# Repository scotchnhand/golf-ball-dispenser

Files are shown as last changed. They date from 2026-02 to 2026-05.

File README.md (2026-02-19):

# Golf Ball Dispenser

An automated golf ball dispenser that detects when you're ready and feeds a ball on demand. Built with 3D printed parts, an Arduino Nano, and off-the-shelf components.
https://youtu.be/GQfpbspkEQ4
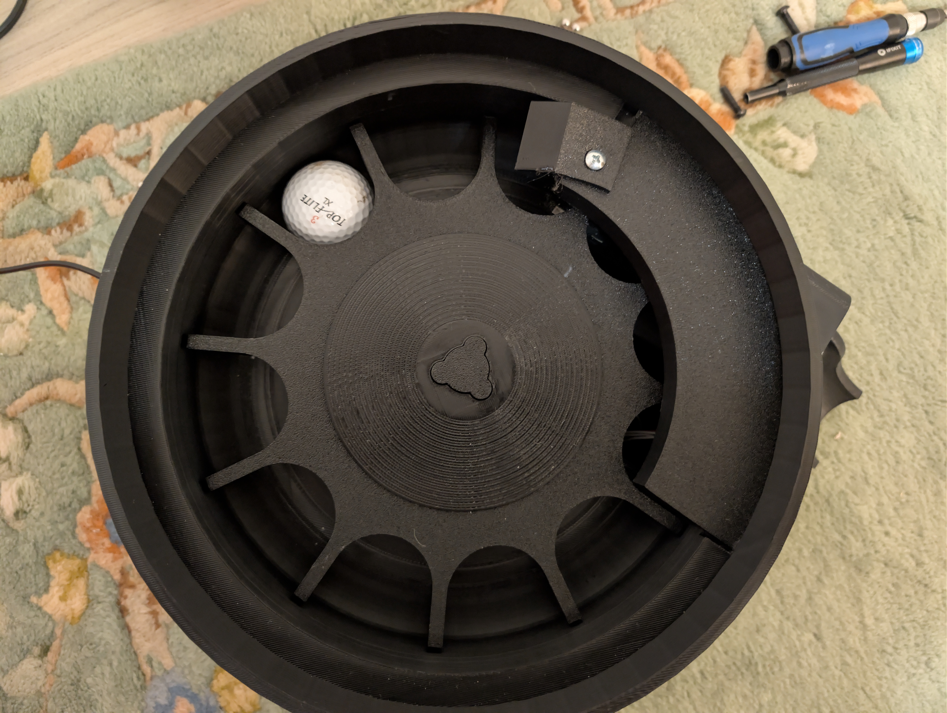
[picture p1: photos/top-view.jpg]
Top View

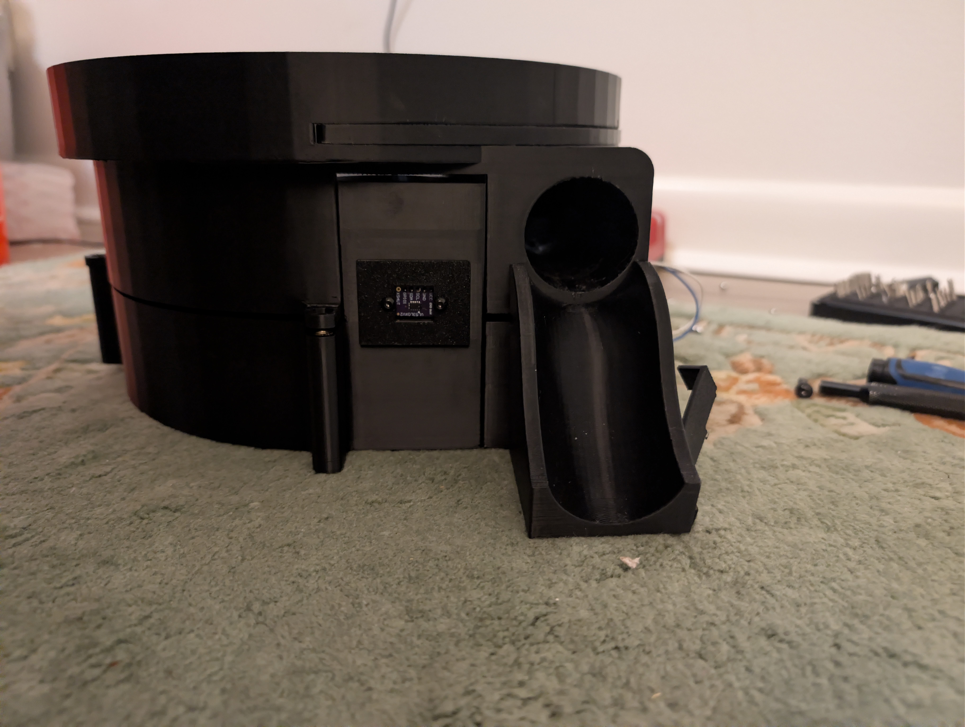
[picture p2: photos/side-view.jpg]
Side View


## How It Works

1. A **VL53L0X Time-of-Flight laser distance sensor** detects when an object (your club or hand) is within 20cm
2. A **DC geared motor** spins a carousel that feeds a single golf ball to the exit chute
3. A **limit switch** detects when the carousel has completed one rotation and stops the motor
4. The system resets and waits for the next trigger

### Safety Features

- **10-second timeout**: Motor stops automatically if the limit switch isn't triggered within 10 seconds
- **Debounced inputs**: Both the limit switch and distance sensor readings are debounced to prevent false triggers
- **Interrupt-driven**: Limit switch uses hardware interrupt for immediate motor stop
- **Limit switch pre-press detection**: If the limit switch is already pressed when a cycle starts, the system waits for it to release before watching for the stop signal

## Wiring Diagram

| Component | Pin | Arduino Nano |
|---|---|---|
| Limit Switch | Signal | D2 |
| VL53L0X | GPIO1 (interrupt) | D3 |
| L298N | IN1 | D5 |
| L298N | IN2 | D6 |
| VL53L0X | SDA | A4 |
| VL53L0X | SCL | A5 |
| VL53L0X | VIN | 5V |
| VL53L0X | GND | GND |
| L298N | 12V | External 12V PSU |
| L298N | GND | Common GND |
| Limit Switch | COM | GND |
| Limit Switch | NO | D2 (uses internal pull-up) |

## Bill of Materials

> **Note:** Many of these parts are interchangeable and can be found on Amazon, eBay, or any electronics supplier. The AliExpress links below are what was used in this build. Prices shown are approximate per-unit costs (many listings sell in multi-packs, so buying just one may cost more).

### Electronics

| # | Component | Qty | Approx. Unit Price | Link |
|---|---|---|---|---|
| 1 | Arduino Nano (ATmega328P) | 1 | ~$2.50 | [AliExpress](https://www.aliexpress.us/item/3256806444439267.html) |
| 2 | L298N Motor Driver Module | 1 | ~$1.50 | [AliExpress](https://www.aliexpress.us/item/3256807078618738.html) |
| 3 | VL53L0X ToF Distance Sensor | 1 | ~$1.80 | [AliExpress](https://www.aliexpress.us/item/3256806179489186.html) |
| 4 | Low RPM DC Geared Motor (12V) | 1 | ~$12.00 | [AliExpress](https://www.aliexpress.us/item/3256805899293106.html) |
| 5 | Micro Limit Switch | 1 | ~$0.20 | [AliExpress](https://www.aliexpress.us/item/3256806027015669.html) |
| 6 | ON/OFF Rocker Switch | 1 | ~$0.30 | [AliExpress](https://www.aliexpress.us/item/2251832837763800.html) |
| 7 | DC Barrel Jack Panel Mount | 1 | ~$0.30 | [AliExpress](https://www.aliexpress.us/item/3256804296022885.html) |
| 8 | 12V 1A AC-DC Power Adapter | 1 | ~$3.00 | [AliExpress](https://www.aliexpress.us/item/3256804346592962.html) |
| 9 | Small Prototype PCB Board | 1 | ~$0.25 | [AliExpress](https://www.aliexpress.us/item/3256801518277095.html) |

### Hardware

| # | Component | Qty | Approx. Unit Price | Link |
|---|---|---|---|---|
| 10 | M5 Heat-Set Inserts (brass) | 7 | ~$0.10 ea | [AliExpress](https://www.aliexpress.us/item/3256809271320211.html) |
| 11 | M5 Screws | 7 | ~$0.05 ea | [AliExpress](https://www.aliexpress.us/item/3256802218134509.html) |
| 12 | M4 Screw + Nut | 1 | ~$0.05 | [AliExpress](https://www.aliexpress.us/item/3256802218134509.html) |
| 13 | M3 Screws | 2 | ~$0.05 ea | [AliExpress](https://www.aliexpress.us/item/3256802218134509.html) |
| 14 | 6mm Steel Ball Bearings / BBs | ~20+ | ~$0.02 ea | [AliExpress](https://www.aliexpress.us/item/3256805859138836.html) |
| 15 | Epoxy | 1 | ~$2.00 | - |

### Wiring / Consumables

| # | Component | Qty | Notes |
|---|---|---|---|
| 16 | JST XH Connectors | 1 set | [AliExpress](https://www.aliexpress.us/item/3256806179489186.html) |
| 17 | Hook-up Wire / Jumper Wire | assorted | Any silicone or dupont wire |
| 18 | Solder | - | Lead-free recommended |

**Estimated total cost: ~$18 - $25** (buying individual components)

> Prices fluctuate on AliExpress. Many of these components are sold in multi-packs, so the per-unit cost can be much lower if you're building multiple units or want spares.

### Tools Required

- **3D Printer** (for printing the enclosure and carousel)
- **Soldering iron** (for heat-set inserts and wiring)
- **Basic hand tools** (screwdrivers, wire strippers)

## 3D Printed Parts

The CAD model is provided as a STEP file (`golfballdispenser.STEP`) which can be opened in any CAD software (Fusion 360, FreeCAD, SolidWorks, etc.). A PDF drawing is also included (`Ball dispenser.pdf`).

### Print Settings (Recommended)

- **Material**: PLA or PETG
- **Layer Height**: 0.2mm
- **Infill**: 15-20%
- **Supports**: Yes (for the exit chute and motor mount)

## Software Setup

### Arduino IDE

1. Open `golf_feeder.ino` in Arduino IDE
2. Install the required library:
   - Go to **Sketch > Include Library > Manage Libraries**
   - Search for **"VL53L0X"** by **Pololu**
   - Install it
3. Select **Board**: Arduino Nano
4. Select **Processor**: ATmega328P (Old Bootloader) if upload fails
5. Upload

### Configurable Parameters

| Parameter | Default | Description |
|---|---|---|
| `TRIGGER_DISTANCE_MM` | 200 | Detection distance in mm (20cm) |
| `MOTOR_TIMEOUT_MS` | 10000 | Safety timeout in ms (10 seconds) |
| `COOLDOWN_TIME_MS` | 500 | Delay before accepting next trigger |
| `SENSOR_READ_INTERVAL_MS` | 100 | Fallback polling interval in ms |

## Photos

See the [photos/](photos/) directory for build photos showing the assembled unit, wiring, and internal components.

## License

This project is open source. Feel free to build, modify, and share.

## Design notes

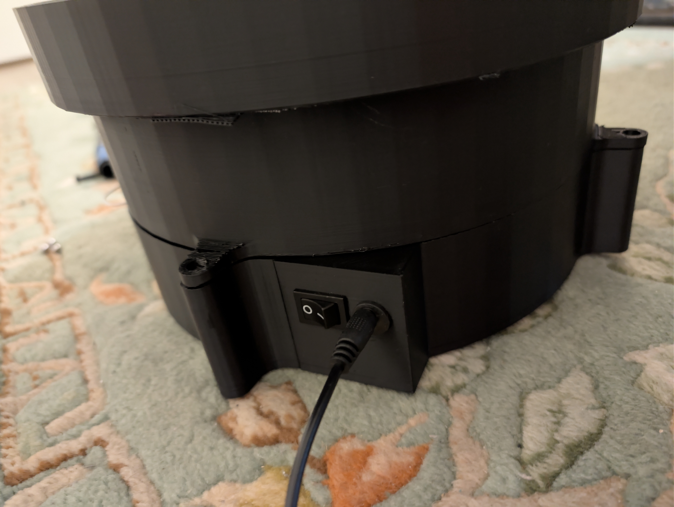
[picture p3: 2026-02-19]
photos/power-input.jpg

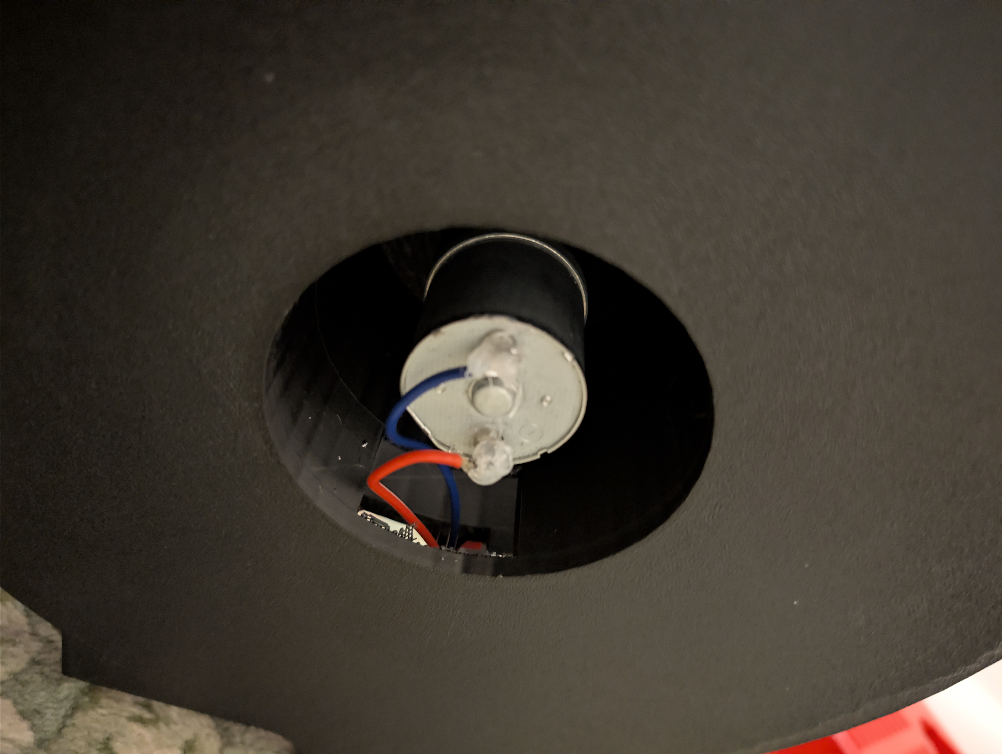
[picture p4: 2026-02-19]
photos/motor-mount.jpg

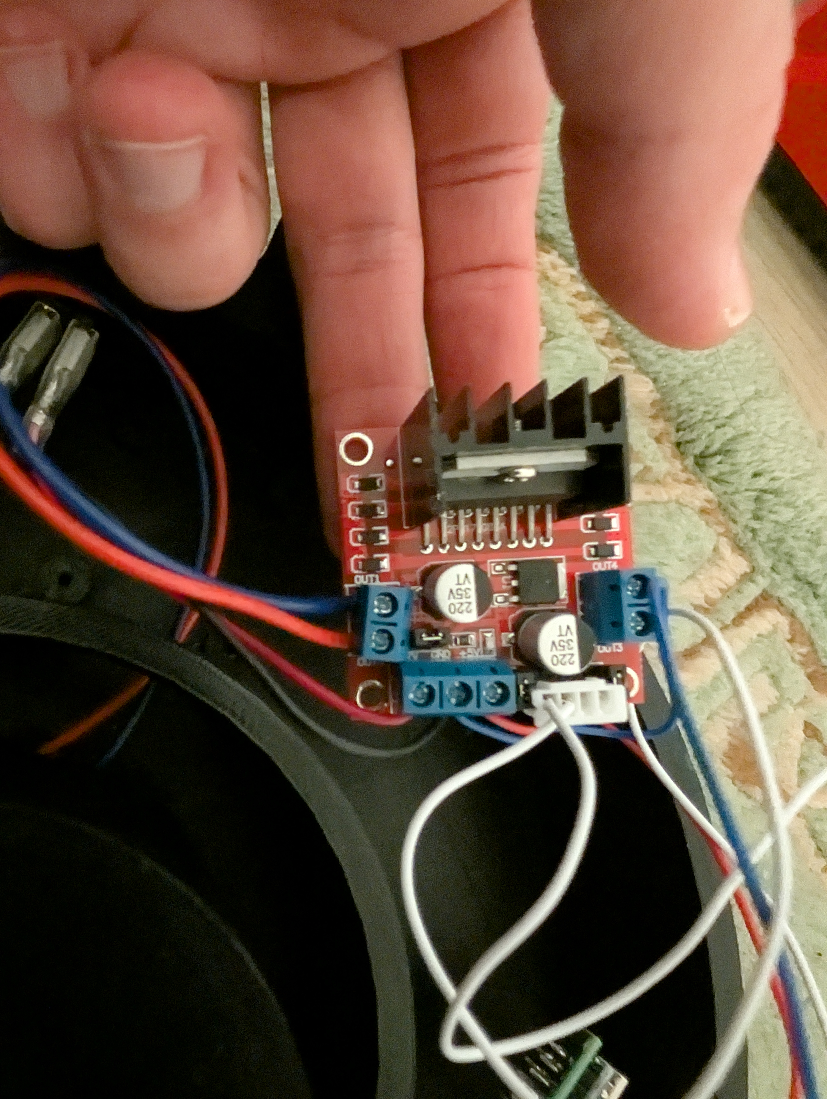
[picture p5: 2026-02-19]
photos/l298n-driver.jpg

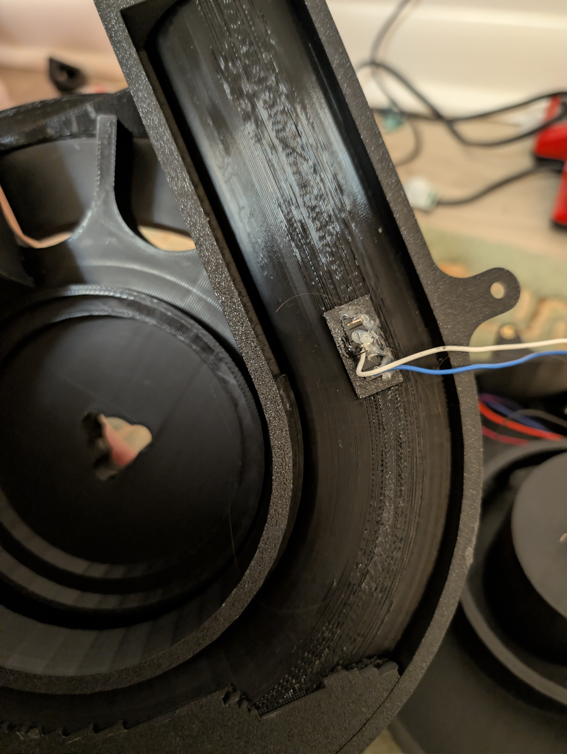
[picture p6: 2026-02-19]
photos/limit-switch-detail.jpg

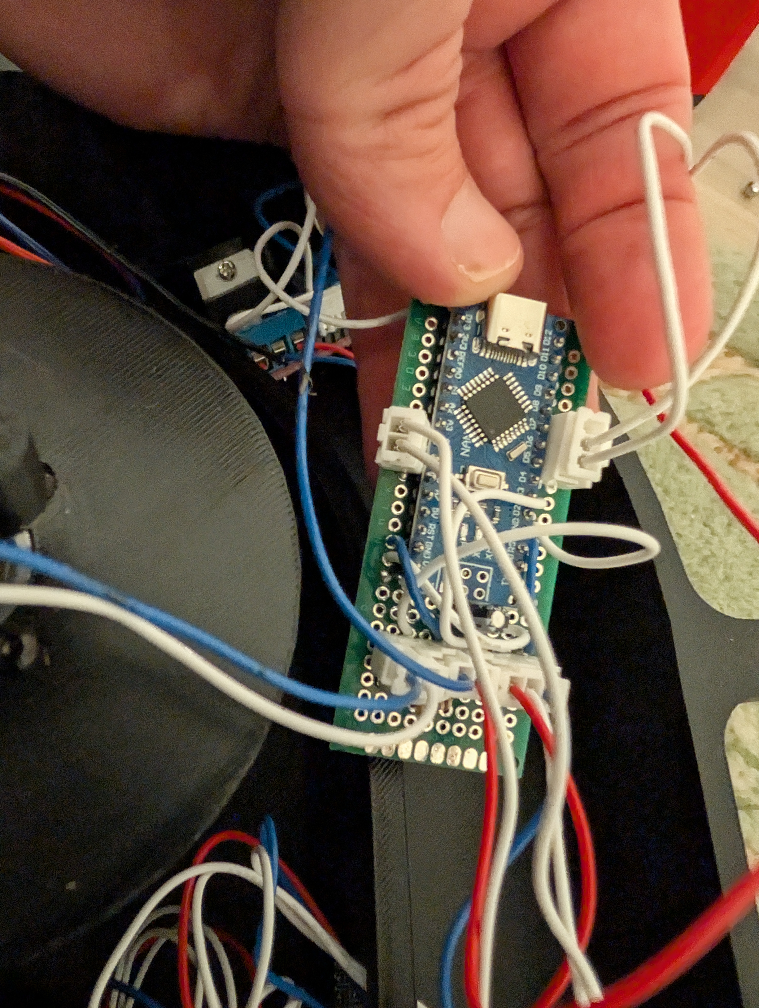
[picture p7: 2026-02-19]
photos/arduino-nano.jpg

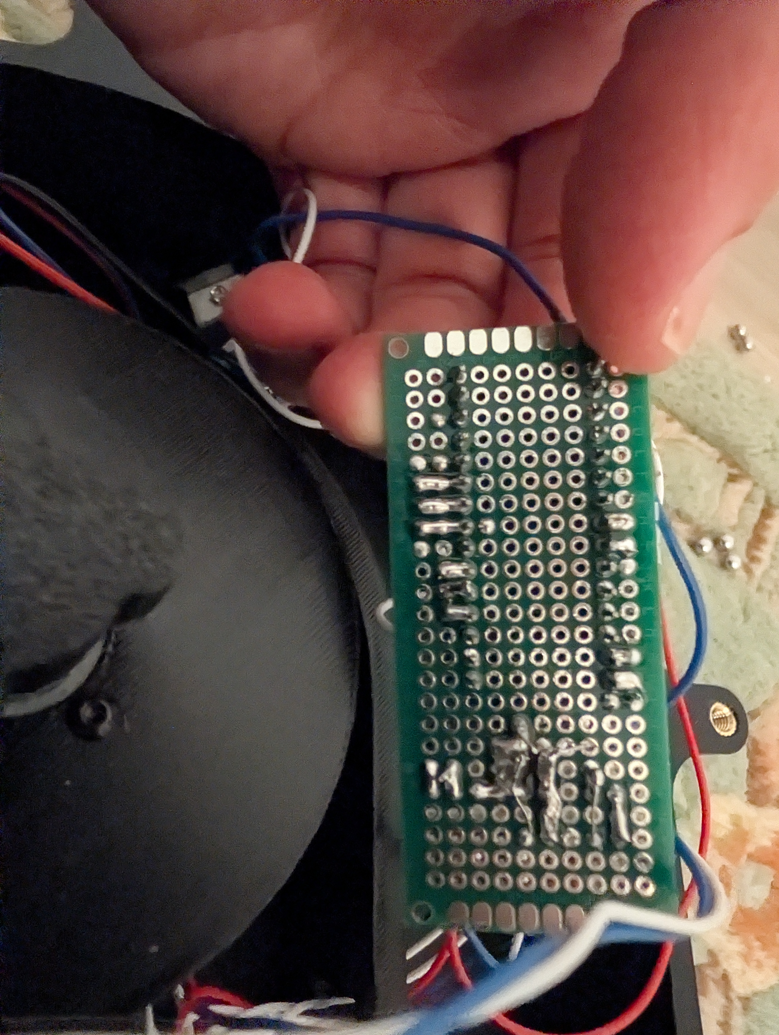
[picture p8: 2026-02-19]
photos/perfboard.jpg

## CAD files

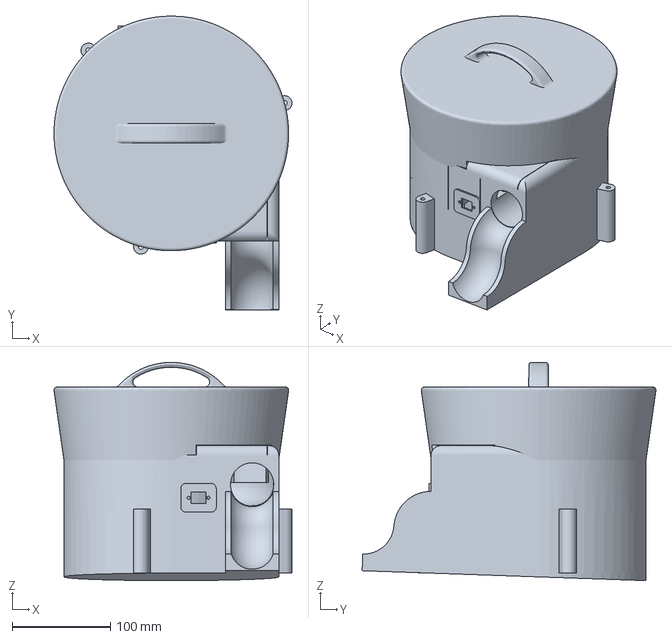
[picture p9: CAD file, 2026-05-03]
Golf ball dispenser less than256 mm.3MF
241.6 x 298.3 x 221.6 mm

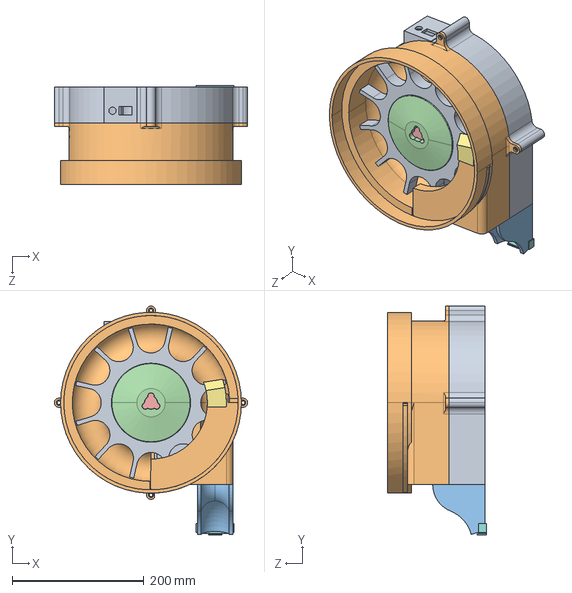
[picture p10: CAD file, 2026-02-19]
golfballdispenser.STEP
294.0 x 348.1 x 150.0 mm

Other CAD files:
dispenser.FCStd

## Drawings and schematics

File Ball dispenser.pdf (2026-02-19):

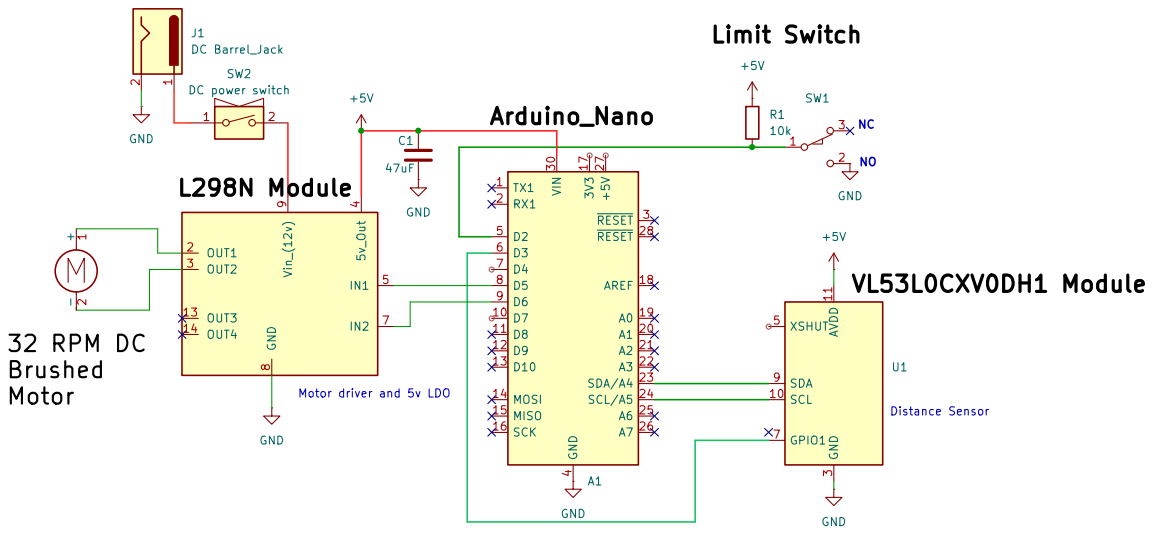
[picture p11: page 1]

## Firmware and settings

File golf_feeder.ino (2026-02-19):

/*
 * Automated Golf Ball Feeder
 *
 * Hardware:
 *   - Arduino Nano
 *   - Limit switch on D2 (INPUT_PULLUP - normally HIGH, LOW when pressed)
 *   - L298N Motor Driver: IN1=D5, IN2=D6
 *   - VL53L0X ToF Distance Sensor:
 *       - I2C: SDA=A4, SCL=A5
 *       - GPIO1 (interrupt) → D3
 *
 * Operation:
 *   - Object detected within 20cm → motor runs
 *   - Limit switch pressed → motor stops immediately
 *   - 10 second timeout safety if limit switch not triggered
 *
 * Library: Install "VL53L0X" by Pololu from Library Manager
 */

#include <Wire.h>
#include <VL53L0X.h>

// Pin definitions
const int PIN_LIMIT_SWITCH = 2;
const int PIN_SENSOR_INT = 3;   // VL53L0X GPIO1 interrupt pin
const int PIN_MOTOR_IN1 = 5;
const int PIN_MOTOR_IN2 = 6;

// Distance threshold (in mm)
const int TRIGGER_DISTANCE_MM = 200;  // 20cm = 200mm

// Timing constants
const unsigned long DEBOUNCE_DELAY_MS = 50;
const unsigned long MOTOR_TIMEOUT_MS = 10000;  // 10 second safety timeout
const unsigned long COOLDOWN_TIME_MS = 500;    // Time to ignore sensor after cycle

// Motor states
enum MotorState {
  MOTOR_STOPPED,
  MOTOR_RUNNING
};

// System states
enum SystemState {
  STATE_IDLE,
  STATE_FEEDING,
  STATE_COOLDOWN
};

// VL53L0X sensor
VL53L0X distanceSensor;
bool sensorInitialized = false;

// Global variables
volatile bool limitSwitchTriggered = false;
volatile bool sensorDataReady = false;
MotorState motorState = MOTOR_STOPPED;
SystemState systemState = STATE_IDLE;
unsigned long motorStartTime = 0;
unsigned long cooldownStartTime = 0;
bool waitingForLimitRelease = false;

// Debounce variables for limit switch
unsigned long lastLimitDebounceTime = 0;
int lastLimitReading = HIGH;
int limitSwitchState = HIGH;

// Distance sensor variables
int currentDistance = 9999;
unsigned long lastSensorReadTime = 0;
const unsigned long SENSOR_READ_INTERVAL_MS = 100;  // Fallback polling interval

void setup() {
  // Initialize serial for debugging
  Serial.begin(9600);
  Serial.println(F("Golf Feeder Starting..."));

  // Configure pins
  pinMode(PIN_LIMIT_SWITCH, INPUT_PULLUP);
  pinMode(PIN_SENSOR_INT, INPUT_PULLUP);  // GPIO1 is active LOW
  pinMode(PIN_MOTOR_IN1, OUTPUT);
  pinMode(PIN_MOTOR_IN2, OUTPUT);

  // Ensure motor is stopped at startup
  stopMotor();

  // Initialize I2C and VL53L0X sensor
  Wire.begin();
  distanceSensor.setTimeout(500);

  if (!distanceSensor.init()) {
    Serial.println(F("ERROR: VL53L0X not found! Check wiring."));
    sensorInitialized = false;
  } else {
    Serial.println(F("VL53L0X initialized successfully"));
    sensorInitialized = true;

    // Configure for continuous mode with interrupt
    // Set GPIO1 to output interrupt on new data ready (active LOW)
    distanceSensor.writeReg(VL53L0X::SYSTEM_INTERRUPT_CONFIG_GPIO, 0x04);  // New sample ready
    distanceSensor.writeReg(VL53L0X::GPIO_HV_MUX_ACTIVE_HIGH,
                            distanceSensor.readReg(VL53L0X::GPIO_HV_MUX_ACTIVE_HIGH) & ~0x10);  // Active LOW

    // Clear any pending interrupt
    distanceSensor.writeReg(VL53L0X::SYSTEM_INTERRUPT_CLEAR, 0x01);

    // Start continuous ranging (50ms between readings)
    distanceSensor.startContinuous(50);
  }

  // Attach interrupts
  attachInterrupt(digitalPinToInterrupt(PIN_LIMIT_SWITCH), limitSwitchISR, FALLING);
  attachInterrupt(digitalPinToInterrupt(PIN_SENSOR_INT), sensorISR, FALLING);

  Serial.println(F("System ready - waiting for object within 20cm..."));
}

void loop() {
  // Check for limit switch interrupt flag first
  if (limitSwitchTriggered) {
    handleLimitSwitch();
  }

  // Check for sensor data ready (interrupt or fallback polling)
  if (sensorDataReady || (millis() - lastSensorReadTime >= SENSOR_READ_INTERVAL_MS)) {
    // Also check if GPIO1 is LOW (data ready) in case we missed the edge
    if (sensorDataReady || digitalRead(PIN_SENSOR_INT) == LOW) {
      readDistanceSensor();
      lastSensorReadTime = millis();
    }
    sensorDataReady = false;
  }

  // Read limit switch state
  readLimitSwitch();

  // State machine
  switch (systemState) {
    case STATE_IDLE:
      handleIdleState();
      break;

    case STATE_FEEDING:
      handleFeedingState();
      break;

    case STATE_COOLDOWN:
      handleCooldownState();
      break;
  }
}

// ISR for limit switch
void limitSwitchISR() {
  limitSwitchTriggered = true;
}

// ISR for VL53L0X data ready
void sensorISR() {
  sensorDataReady = true;
}

// Handle limit switch trigger (called from main loop)
void handleLimitSwitch() {
  if (millis() - lastLimitDebounceTime > DEBOUNCE_DELAY_MS) {
    if (digitalRead(PIN_LIMIT_SWITCH) == LOW) {
      if (motorState == MOTOR_RUNNING && !waitingForLimitRelease) {
        Serial.println(F("Limit switch triggered - stopping motor"));
        stopMotor();
        enterCooldown();
      }
    }
    lastLimitDebounceTime = millis();
  }
  limitSwitchTriggered = false;
}

// Debounced limit switch reading
void readLimitSwitch() {
  int reading = digitalRead(PIN_LIMIT_SWITCH);

  if (reading != lastLimitReading) {
    lastLimitDebounceTime = millis();
  }

  if ((millis() - lastLimitDebounceTime) > DEBOUNCE_DELAY_MS) {
    if (reading != limitSwitchState) {
      limitSwitchState = reading;

      if (waitingForLimitRelease && limitSwitchState == HIGH) {
        waitingForLimitRelease = false;
        Serial.println(F("Limit switch released - now watching for press"));
      }
      else if (limitSwitchState == LOW && motorState == MOTOR_RUNNING && !waitingForLimitRelease) {
        Serial.println(F("Limit switch pressed - stopping motor"));
        stopMotor();
        enterCooldown();
      }
    }
  }

  lastLimitReading = reading;
}

// Read distance from sensor (called when interrupt fires)
void readDistanceSensor() {
  if (!sensorInitialized) {
    return;
  }

  // Read the distance
  uint16_t range = distanceSensor.readRangeContinuousMillimeters();

  // Clear the interrupt (write twice to ensure it clears)
  distanceSensor.writeReg(VL53L0X::SYSTEM_INTERRUPT_CLEAR, 0x01);
  distanceSensor.writeReg(VL53L0X::SYSTEM_INTERRUPT_CLEAR, 0x01);

  // Check for timeout/error (returns 65535 on error)
  if (distanceSensor.timeoutOccurred() || range > 8000) {
    currentDistance = 9999;
  } else {
    currentDistance = range;
  }
}

// Handle idle state - waiting for object detection
void handleIdleState() {
  if (!sensorInitialized) {
    return;
  }

  if (currentDistance < TRIGGER_DISTANCE_MM && currentDistance > 0) {
    Serial.print(F("Object detected at "));
    Serial.print(currentDistance);
    Serial.println(F("mm - starting feed cycle"));

    if (digitalRead(PIN_LIMIT_SWITCH) == LOW) {
      waitingForLimitRelease = true;
      Serial.println(F("Limit switch already pressed - waiting for release"));
    } else {
      waitingForLimitRelease = false;
    }

    startMotor();
    systemState = STATE_FEEDING;
    motorStartTime = millis();
  }
}

// Handle feeding state - motor running
void handleFeedingState() {
  if (millis() - motorStartTime >= MOTOR_TIMEOUT_MS) {
    Serial.println(F("TIMEOUT: Limit switch not triggered in 10 seconds - stopping motor"));
    stopMotor();
    enterCooldown();
    return;
  }
}

// Handle cooldown state - wait before accepting new triggers
void handleCooldownState() {
  if (millis() - cooldownStartTime >= COOLDOWN_TIME_MS) {
    if (currentDistance >= TRIGGER_DISTANCE_MM || currentDistance == 0) {
      Serial.println(F("Ready for next trigger"));
      systemState = STATE_IDLE;
    }
  }
}

// Enter cooldown after feed cycle completes
void enterCooldown() {
  systemState = STATE_COOLDOWN;
  cooldownStartTime = millis();
}

// Start motor
void startMotor() {
  digitalWrite(PIN_MOTOR_IN1, LOW);
  digitalWrite(PIN_MOTOR_IN2, HIGH);
  motorState = MOTOR_RUNNING;
  Serial.println(F("Motor started"));
}

// Stop motor immediately
void stopMotor() {
  digitalWrite(PIN_MOTOR_IN1, LOW);
  digitalWrite(PIN_MOTOR_IN2, LOW);
  motorState = MOTOR_STOPPED;
  Serial.println(F("Motor stopped"));
}

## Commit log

2026-02-19 Initial release: Automated Golf Ball Dispenser
    Open source release including Arduino firmware, 3D CAD model (STEP),
    technical drawing (PDF), build photos, and full bill of materials.
    [golfballdispenser.STEP]
2026-02-19 Update BOM with accurate component list and quantities
    Corrected hardware section with exact screw counts (7x M5, 1x M4, 2x M3),
    heat-set inserts, steel ball bearings, epoxy, AC-DC adapter, and separated
    into Electronics, Hardware, and Wiring/Consumables sections.
2026-02-19 Update price for Low RPM DC Geared Motor
2026-05-03 Add files via upload
    Added bambu and standard print accessinble version
    [Golf ball dispenser less than256 mm.3MF]
2026-05-30 Add CLAUDE.md with developer guidance
    This file provides comprehensive documentation for future Claude Code instances
    working on this Arduino golf ball dispenser project, including:
    - Development setup and Arduino IDE configuration
    - State machine architecture and control flow
    - Hardware pin mapping and wiring details
    - Safety features and interrupt-driven design
    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
2026-06-03 Add FreeCAD dispenser and split_output.log
    Add new FreeCAD project file (dispenser.FCStd) and accompanying runtime log (split_output.log). The log captures environment variables, FreeCAD startup output, a missing 3Dconnexion framework error, a deprecation warning to use ImportGui for STEP imports, and an encoding exception while processing split_model.FCMacro (ascii codec can't encode '✗'). Includes STEP file splitter header and progress output.
    [dispenser.FCStd]
